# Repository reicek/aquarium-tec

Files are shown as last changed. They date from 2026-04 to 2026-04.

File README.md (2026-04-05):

# Aquarium TEC Cold Block Prototype

This repository contains the current engineering baseline for a custom inline TEC chiller for an 8 gallon aquarium. The project is built around a low-restriction cold block, a staged prototype-to-CNC manufacturing path, and a first powered prototype that keeps the controller, HMI, and high-current TEC hardware explicit and orderable.

## What This Repo Holds

- A parametric OpenSCAD model for the cold block, hose-plug options, and interlocking powered-prototype support kit.
- Reference SVG sheets for the mechanical design and the powered-prototype electrical package.
- BOM, RFQ, validation, and controller-planning documents under `agent/` and `rfq/`.
- Quote-ready notes for both the PLA fit prototype and the final hybrid CNC wet-part set.

## Current Baseline

Mechanical baseline:

- Inline cold block body: 140 x 92 x 24 mm, excluding hose plugs.
- Internal water path: 6 straight channels with a 14.5 mm minimum bore through the full path.
- Lid/base split: 8 mm lid, 16 mm base.
- Thermal stack: 50 x 50 mm TEC, 60 x 60 x 5 mm copper spreader, Intel LGA1700 / LGA1851 hot-side mount.
- Hose-plug baseline: separate trapped plugs, with the current documentation assuming the 16.0 mm OD option on both ports.
- Final wet-part direction: 316L stainless lid, CNC POM base, and CNC POM hose plugs.

Powered prototype baseline:

- Main PSU: Mean Well LRS-350-24.
- TEC driver: IBT-2 Double BTS7960 43 A module.
- Logic buck: TOBSUN EA15-5V, 24 V to 5 V, 3 A.
- Controller: Seeed Studio XIAO nRF52840 Plus.
- Local HMI: Seeed Studio Round Display for XIAO.
- Hot-side cooler: Thermalright Assassin X 120 Refined SE.
- Hot-side fan: Noctua NF-F12 industrialPPC-24V-2000 IP67 PWM.
- Sensors: DS18B20 set, Adafruit SHT31-D, DFRobot SEN0205, and Mallory PS-580Q local alarm.

Prototype rules that remain important:

- The printed wet-path parts are for fit and dry assembly only.
- The 24 V and 5 V rails are the only rails in the current exact powered-prototype package.
- The final hose-plug OD is still gated on physical hose-fit testing.

## Key Docs

- [tec_cold_block_mockup.scad](tec_cold_block_mockup.scad): source-of-truth OpenSCAD model.
- [fabrication_notes.md](fabrication_notes.md): high-level geometry, usage, and file notes.
- [agent/mechanical_design.md](agent/mechanical_design.md): frozen geometry, support-frame intent, and manufacturing notes.
- [agent/system_bom.md](agent/system_bom.md): working BOM.
- [agent/powered_prototype_order_list.md](agent/powered_prototype_order_list.md): current buy-list freeze for the powered prototype.
- [agent/powered_prototype_wiring_diagram.md](agent/powered_prototype_wiring_diagram.md): harness IDs, cut lengths, and wiring topology.
- [agent/validation_and_open_items.md](agent/validation_and_open_items.md): validation gates and still-open items.
- [rfq/pla_prototype/pla_prototype_rfq_package.md](rfq/pla_prototype/pla_prototype_rfq_package.md): PLA prototype package.
- [rfq/final_hybrid_cnc/final_hybrid_cnc_rfq_package.md](rfq/final_hybrid_cnc/final_hybrid_cnc_rfq_package.md): final hybrid CNC package.

3D Renders



- Side


- Top


- Front


- Back


## SVG Gallery

### Whole Block Reference

Shows the assembled cold block reference view.

Whole block reference

### Lid Reference

Shows the lid-owned geometry, channel pack, and thermal face role.

Cold block lid reference

### Base Reference

Shows the base-owned geometry, seal groove, and lower water-path role.

Cold block base reference

### Hose-Plug Options

Shows the current 16.0 mm, 15.4 mm, and 14.8 mm hose-plug options.

Hose plug options reference

### Combined Cold Block Overview

Shows the block, lid, base, and hose-plug option set in one reference sheet.

Combined cold block overview

### Powered Prototype Component Layout

Shows the 2D component placement baseline for the powered prototype support assembly.

Powered prototype component layout

### Powered Prototype Electrical Block Sheet

Shows the detailed color-coded wiring diagram for the same powered prototype baseline.

Powered prototype electrical block sheet

## Manufacturing Path

Stage 1, PLA fit prototype:

- Validate hose fit, assembly access, clamp access, support-frame part fit, and service clearance.
- Do not use the printed cold block as the final wet-path part.

Stage 2, final hybrid CNC wet parts:

- Machine the lid from 316L stainless steel.
- Machine the base and hose plugs from POM.
- Keep the full-bore path and smooth diffuser/converger surfaces.
- Hold final wet-part release until hose-plug fit is locked from the real hose.

## Export And Verification

Available VS Code tasks include:

- `Export OpenSCAD Prototype STL Set`
- `Verify OpenSCAD Prototype STL Layouts`
- `Export OpenSCAD Prototype Support Service STL Set`
- `Export OpenSCAD Hybrid STL Set`
- `Export OpenSCAD Hybrid STEP Set`

Useful output folders:

- [rfq/pla_prototype/stl](rfq/pla_prototype/stl)
- [rfq/pla_prototype/exports](rfq/pla_prototype/exports)
- [rfq/final_hybrid_cnc/stl](rfq/final_hybrid_cnc/stl)
- [rfq/final_hybrid_cnc/step](rfq/final_hybrid_cnc/step)

## Open Gates

- Final hose-plug OD still depends on real hose-fit results.
- Final clamp size still depends on the chosen hose-plug OD and real hose measurements.
- Final wet-part seal cut length still depends on the released groove measurement.
- The controller PCB is still a planned deliverable, not a finished schematic/layout release.
- Leak-threshold calibration still remains a firmware and bring-up task.

## Practical Reading Order

1. Start with [fabrication_notes.md](fabrication_notes.md) for the repo overview.
2. Read [agent/mechanical_design.md](agent/mechanical_design.md) for the frozen geometry and support-frame intent.
3. Read [agent/system_bom.md](agent/system_bom.md) and [agent/powered_prototype_order_list.md](agent/powered_prototype_order_list.md) for the current hardware baseline.
4. Read [agent/powered_prototype_wiring_diagram.md](agent/powered_prototype_wiring_diagram.md) together with the two powered-prototype SVG sheets.
5. Use the RFQ packages when preparing quotes or exports.

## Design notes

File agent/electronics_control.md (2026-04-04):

# Electronics And Control

This file describes the preferred electrical architecture for the prototype and the path to a cleaner production-style build.

## Control architecture philosophy

First revision should separate logic and sensing from the high-current TEC power stage.

Recommended split:

- XIAO nRF52840 Plus plus Round Display handle local HMI, BLE telemetry, and core control logic
- custom interface or interposer board handles sensor connectors, conditioned driver signals, power entry, and access to the Plus-only additional pads
- external TEC driver handles 24 V power switching in the first revision

Why:

- lower integration risk
- easier PCBWay assembly
- easier bench debugging
- avoids forcing the first custom PCB to solve both logic and power-stage problems at the same time

## Power tree

Recommended structure:

- 24 V main input from PSU
- direct 24 V branch to TEC driver
- fused low-current 24 V branch to the logic buck
- 24 V to 5 V buck for the XIAO, Round Display, and low-current logic rail
- direct 24 V branch to the current prototype fan
- no 12 V rail in the current exact prototype build; keep a 24 V to 12 V buck only as a fallback if the stock 12 V cooler fan is reinstated later

Important constraint:

- raw 24 V must not be routed to the XIAO Plus or Round Display; the powered prototype must pass through the 24 V to 5 V logic buck first

Practical baseline parts:

- main PSU: Mean Well LRS-350-24, approved project baseline PSU
- logic converter: TOBSUN EA15-5V, required for the powered prototype until the controller board exists
- hot-side fan path: Thermalright Assassin X 120 Refined SE heatsink with a Noctua NF-F12 industrialPPC-24V-2000 IP67 PWM replacement fan
- optional fallback fan converter: Pololu D24V10F12 only if the stock 12 V cooler fan is kept instead of the 24 V Noctua replacement

Logic power budget note:

- the Round Display itself is low power, but the total 5 V budget should assume XIAO, display, sensors, and interface buffer overhead
- a 5 V rail sized for at least 500 mA continuous is comfortable; 1 A is preferred margin

## TEC driver strategy

Approved prototype baseline:

- external IBT-2 Double BTS7960 43A H-bridge module

Current engineering stance:

- approved for the first powered prototype
- not automatically trusted for long-term continuous-duty use

Important issue:

- the XIAO Plus is 3.3 V logic only
- many generic driver modules are sold as 5 V logic accessories
- do not assume logic compatibility without verification

Engineering recommendation:

- either verify the driver input thresholds on the exact module used
- or insert a proper logic-level translator / buffer between XIAO and driver
- the preferred rev-1 solution is a Texas Instruments SN74AHCT125PW powered from 5 V; treat it as standard in rev 1 unless the received IBT-2 board is fully verified for 3.3 V logic and safe defaults

## Control method

Do not use relays for TEC power modulation.

Use:

- transistorized driver stage
- PWM or current-modulated control through the driver

Prototype control notes:

- the TEC does not need polarity reversal for a pure cooling system, but an H-bridge keeps that option available
- if future integration prefers a simpler direction, a one-quadrant power stage could replace the H-bridge later

## Recommended sensors

Recommended rev-1 temperature set:

- one water temperature sensor for actual aquarium temperature control
- one hot-side sensor on the CPU cooler base or near the hot plate
- one cold-block sensor on the exchanger body
- one air intake temperature sensor placed upstream of the cooler fan and used as the ambient intake reference
- one air outlet temperature sensor placed in the cooler exhaust stream

Strongly recommended additional sensors:

- ambient humidity sensor near the insulated block to watch condensation risk
- leak sensor in the cabinet or below the block

Why the extra air sensors are worth adding:

- intake air temperature gives a real ambient baseline for hot-side performance and condensation calculations
- outlet air temperature gives a quick check on heatsink delta and airflow health
- intake-to-outlet trend data helps catch fan failure, fin blockage, or exhaust recirculation earlier than the base sensor alone

Recommended sensor types:

- Adafruit Waterproof DS18B20, PID 381, for water temperature unless the stock probe already on hand is reused
- Analog Devices DS18B20+ in TO-92 package for the hot side
- Analog Devices DS18B20+ in TO-92 package for the cold block
- Analog Devices DS18B20+ in TO-92 package for intake air
- Analog Devices DS18B20+ in TO-92 package for outlet air
- Adafruit SHT31-D breakout, PID 2857, for ambient condensation monitoring
- DFRobot Gravity Water Sensor, SEN0205, as the current exact prototype leak-sensor choice

Rev-1 integration recommendation:

- standardize water, cold-block, hot-side, intake-air, and outlet-air on one shared 1-Wire bus
- DS18B20 is now the chosen rev-1 temperature family for all five points
- exact attachment method for the hot-side and cold-block sensors is still a mechanical packaging detail, but no extra analog temperature channel is planned

Bus-sharing note:

- the Round Display already occupies D4 and D5 for I2C-based RTC and touch functions
- the humidity sensor can still share this I2C bus if pull-ups and address assignments are kept sensible
- a shared DS18B20 bus lets water, cold-block, hot-side, intake-air, and outlet-air probes share a single extra GPIO on the Plus-only pad set
- use the SEN0205 as the current exact leak-sensor part for the dry-build prototype and treat the controller-side channel as a thresholded leak input during harness bring-up

## Safety and fail-safe behaviors

The controller should be designed around fault containment, not just temperature control.

Minimum failsafes:

- if hot-side temperature exceeds threshold, reduce or stop TEC drive
- if water temperature sensor becomes invalid, stop TEC drive and raise alarm
- if hot-side temperature rises while the outlet-air minus intake-air delta collapses, assume airflow trouble and reduce or stop TEC drive
- if intake air temperature is unusually high, derate expected cooling capacity or raise an operator warning
- if humidity rises to condensation-risk levels, limit cooling aggressiveness or alarm
- if leak sensor trips, stop TEC and alarm
- if XIAO watchdog triggers, force the TEC driver to a safe disabled state

Electrical protection recommendations:

- branch fuses
- reverse-polarity protection on the low-current logic input
- TVS or surge protection on external sensor lines if they are long
- pull-down or pull-up states that leave the TEC disabled by default at MCU reset

## XIAO Plus and Round Display architecture

The control subsystem should be treated as an HMI stack plus an interface board, not a bare XIAO dev board.

Preferred architecture:

- U1: Seeed Studio XIAO nRF52840 Plus
- U2: Seeed Studio Round Display for XIAO
- PCB1: custom interface or interposer board assembled by PCBWay
- U3: external TEC driver module in prototype phase

Interface-board purpose:

- mount or interconnect the XIAO Plus cleanly
- preserve or replicate the standard XIAO header geometry needed by the Round Display
- break out the Plus-only additional pads to usable connectors or nets
- provide regulated power distribution
- provide driver interface conditioning
- expose SWD pads and debugging access
- keep antenna area clear

Recommended board philosophy:

- 4-layer FR-4
- ENIG finish
- good ground reference for logic and sensor work
- keep high current off this board in revision 1

What the board should include:

- XIAO Plus module footprint using the official Seeed module data
- mating geometry for the Round Display based on the standard XIAO pin rows
- 24 V input connector for auxiliary power only, not TEC current path
- 5 V buck stage or a clearly documented 5 V input path from an external buck module; for the current powered prototype, the external TOBSUN EA15-5V module is mandatory
- JST-VH for the 24 V auxiliary input, JST-PH for low-current sensor I/O, and JST-XH for the driver-control link
- one dedicated 3-pin temperature-bus connector for the shared five-probe DS18B20 harness
- separate low-current connectors for humidity and leak sensing
- 1-Wire pull-up and a serviceable harness plan for the five DS18B20 temperature channels
- SN74AHCT125PW driver-interface buffer
- driver control connector
- alarm output
- Tag-Connect TC2030 compatible SWD pads
- optional local user button if not relying entirely on the touch display

What the board should not do in rev 1:

- switch 6 A TEC current directly unless the whole board is redesigned as a real power board
- crowd the XIAO antenna with planes, shields, or metal standoffs

## Round Display pin budget impact

The Round Display consumes almost the full standard XIAO header pin set.

Pins used by the Round Display stack:

- D1: LCD_CS
- D3: LCD_DC
- D4: I2C SDA for touch and RTC
- D5: I2C SCL for touch and RTC
- D7: touch interrupt
- D2: microSD chip select
- D8, D9, D10: SPI for microSD
- D6: screen backlight control on the display board when the KE switch is in the display position
- D0: battery measurement path on the display board when the KE switch is in the display position

Implication:

- standard XIAO nRF52840 is too pin-starved for this project once the Round Display is added
- XIAO nRF52840 Plus is the correct variant because the additional pads can carry the non-HMI system I/O

## Suggested system I/O allocation

This is the schematic-planning map for rev 1.

- Standard XIAO pins reserved for Round Display: D1, D2, D3, D4, D5, D7, D8, D9, D10, and likely D6 and D0 depending the display switch position used
- Plus-only extra pad 1: 1-Wire temperature bus for water, cold-block, hot-side, intake-air, and outlet-air DS18B20 probes
- Plus-only extra pad 2: leak sensor input
- Plus-only extra pad 3: TEC_PWM to driver buffer
- Plus-only extra pad 4: TEC_EN to driver buffer
- Plus-only extra pad 5: TEC_DIR or second PWM line to driver buffer
- Plus-only extra pad 6: buzzer or alarm output
- Plus-only extra pad 7: fan tach input
- Plus-only extra pad 8: fan PWM output or spare digital output
- Plus-only extra pad 9: spare service input, interlock, or future flow switch

Exact mapping of these functions to the official Plus pad names should follow Seeed's official symbol and footprint during actual schematic capture.

Exact mechanical attachment of the hot-side and cold-block DS18B20 sensors should be decided during packaging, not during pin-budget planning.

## Preferred DS18B20 connector and harness layout

Board-side connector strategy:

- use one board-side connector for the shared temperature bus, not five parallel temperature connectors on the PCB
- recommended connector class for the rev-1 temperature bus: keyed 3-pin JST-PH class or equivalent serviceable locking connector
- pin order should be fixed and documented as 3V3, 1WIRE_TEMP, GND

Harness strategy:

- run the five temperature points in powered 3-wire mode, not parasite-power mode
- use one main 24 to 26 AWG three-conductor harness from the controller board to a splice point near the prototype support frame and thermal assembly
- from that splice point, make four short local drops to cold-block, hot-side, intake-air, and outlet-air sensors
- make the water-temperature branch the only longer run and route it with the hose or water line path instead of letting it dangle near the fan wiring
- label each branch clearly as T_WATER, T_COLD, T_HOT, T_AIR_IN, and T_AIR_OUT

Practical routing rules:

- keep the four local air and block sensor branches as short as practical so the 1-Wire bus behaves like one trunk with short stubs rather than a large star
- keep the humidity and leak wiring off the temperature harness entirely
- place the single 1-Wire pull-up on the controller board only; do not duplicate pull-ups in the harness or sensor pigtails
- keep the temperature harness on the sensor edge of the board, away from the TEC driver wiring bundle

## Rev-1 DS18B20 placement and lead targets

Reference routing point:

- place S_TEMP on the inside face of the rear panel, centered in X, below the driver shelf and about 25 to 35 mm above the top of the block
- treat all local branch lengths below as measured from S_TEMP to the active sensing tip, not from J3
- target branch lengths should include one small service loop but should not leave large unused coils near the fan or driver wiring

Temperature harness target lengths:

- H_TEMP trunk from J3 to S_TEMP: 280 mm target
- T_WATER branch: 1200 mm target, then trim only after the full tank and cabinet routing is confirmed
- T_COLD branch: 200 mm target
- T_HOT branch: 180 mm target
- T_AIR_IN branch: 220 mm target
- T_AIR_OUT branch: 100 mm target

Exact rev-1 mounting locations:

- T_WATER: immerse in the display tank at mid-depth, away from the return jet and away from the cold block assembly, with the sensing tip at least 100 mm from the filter return stream and not resting on the glass or substrate
- T_COLD: bond to the display-side outer wall of the cold-block body, centered on the straight-channel region at about mid-length of the block, roughly 8 to 10 mm above the block bottom and safely below the lid-base split plane
- T_HOT: bond to the exposed cooler-base shoulder or first heat-pipe root zone, on the side of the base that remains accessible after the fan is installed, with the sensing tip as close as practical to the copper spreader plane and kept out of the direct fin-pack airflow
- T_AIR_IN: suspend the sensing tip in the intake gap between the display mast side and the cooler fan face, about 12 to 15 mm ahead of the fan intake plane and about 20 to 25 mm off the fan hub center so it sees moving air instead of the dead zone at the hub
- T_AIR_OUT: suspend the sensing tip in the exhaust gap between the cooler rear face and the PSU side, about 3 to 5 mm behind the rear fin face and about 20 to 25 mm off the hub center, without letting the probe touch the PSU panel, rear shelf, or fin edges

Mounting method guidance:

- T_COLD and T_HOT should use a thin bonded attachment method such as thermally conductive epoxy, aluminum tape plus strain relief, or a compact clamped tab that does not add much thermal mass
- T_AIR_IN and T_AIR_OUT should be supported by a light clip, loom tie, or heat-shrink standoff so the sensing tip sits in the airstream and not against metal or ABS
- T_WATER should use its factory waterproof encapsulation directly and should not share a cable sleeve with the TEC power wiring

## Wireless design note

The stainless block, CPU cooler, PSU, and enclosure metal can all hurt BLE performance.

Design implication:

- place the XIAO near a plastic wall or open air edge of the enclosure
- keep the antenna end away from the wet block and away from large ground pours
- if necessary, use a short cable to physically separate the controller board from the thermal assembly

## Preferred bring-up order

1. power the XIAO and sensors from a bench supply or the TOBSUN EA15-5V logic buck only
2. validate Round Display bring-up using the Arduino GFX or Seeed_GFX path
3. validate sensor readings and BLE behavior
4. connect the external TEC driver with no TEC attached
5. verify safe default states and PWM behavior through the level-shift or buffer stage
6. attach the TEC and hot-side cooling
7. enable thermal testing with water loop last

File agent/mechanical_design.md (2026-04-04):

# Mechanical Design

This file captures the current frozen geometry and the manufacturing intent for the inline cold block.

## Current geometry

Overall body, excluding hose plugs:

- length: 140 mm
- width: 92 mm
- total thickness: 24 mm
- lid thickness: 8 mm
- base thickness: 16 mm

Thermal landing:

- landing area: 64 x 64 mm
- critical flat contact zone: at least 52 x 52 mm
- intended TEC size: 50 x 50 mm
- intended copper spreader size above TEC: 60 x 60 x 5 mm
- hot-side cooler mount pattern: Intel LGA1700 / LGA1851, 78 x 78 mm square, 4.3 mm clearance holes

Water cavity:

- cavity envelope: 112 x 62 x 6 mm
- roof thickness above cavity: 2 mm nominal
- internal side wall thickness: 0 mm dedicated side walls
- inlet diffuser length: 28 mm
- outlet converger length: 28 mm

Channel pack:

- 6 channels
- each channel: about 8.67 x 56 x 6 mm
- fin width between channels: 2 mm
- side walls removed so the outer channels run to the cavity edges
- total open area in channel pack: about 312 mm^2

Hydraulic comparison:

- target hose ID: 14.5 mm
- hose area at 14.5 mm ID: about 165 mm^2
- channel pack open area: about 312 mm^2

Conclusion:

- the channel pack is not supposed to be the hydraulic bottleneck
- the internal bore and transition quality matter more than adding more channels

## Hose plugs and bore

Current SCAD / prototype baseline:

- the preview model now shows separate trapped hose plugs
- hose-plug projection on the full prototype preview: 24 mm
- installed main hose-plug OD: 16.0 mm
- extra hose-plug option ODs: 15.4 mm and 14.8 mm
- minimum internal bore: 14.5 mm
- port axis offset: about 1.25 mm below the lid/base split plane to preserve lid roof thickness

Final wet-part direction:

- use separate replaceable hose-plug pieces, one per port
- trap each hose plug between lid and base so it cannot move in or out while the block is clamped
- use a rounded-square or four-flat anti-rotation interface rather than a sharp square corner
- keep the full 14.5 mm minimum bore through each hose plug and blend smoothly into the diffuser / converger
- keep the hose-clamp bead close to the block face so hose bending load does not create a long moment arm at the plug root

Design intent:

- smooth outside for hose fit
- no barbed geometry that forces a hidden bore restriction
- use external clamp retention rather than aggressive barb teeth
- allow hose-plug OD changes later without remachining the lid

## Seal concept

Current groove baseline:

- groove centerline rectangle: 116 x 68 mm
- groove width: 2.4 mm
- groove depth: 1.5 mm
- intended seal cross section: 2 mm

Seal direction:

- prototype phase can use seal cord or gasket-equivalent for fit confirmation
- final hybrid phase should use EPDM or silicone compatible with aquarium use
- if the final rectangular O-ring is not easy to source, seal cord or custom gasket is acceptable as long as compression is controlled
- do not rely on tapped plastic alone for clamp load; use through-bolts, washers, and compression control across the POM base

## Material strategy

Prototype geometry validation:

- PLA is preferred for the first low-cost fit, size, clamp access, and general assembly checks
- if PCBWay process selection makes PLA awkward, ABS or another rigid prototype plastic is acceptable for fit-only work

Final wet-part baseline:

- lid: 316L stainless steel
- base: CNC POM
- separate hose plugs: CNC POM

Materials explicitly avoided in the water path:

- aluminum
- brass
- mixed unknown plated fittings
- coated 3D-printed wet parts as final-release hardware

## Surface finish and tolerance intent for the final hybrid part

Because this is a wet precision prototype, the surface requirements should be explicit.

Critical zones:

- TEC landing face in the lid: flat and smooth, target flatness 0.05 mm or better, target finish Ra 0.8 um or better
- bore transitions and diffuser surfaces: deburred and polished, no chatter ridges left in the flow path
- O-ring groove in the POM base: clean and burr-free, with no rolled edges that could damage the seal
- hose-plug outside surfaces and bead geometry: smooth and dimensionally stable for hose fit

Preferred wet-part post-process:

- deburr all edges
- hand polish the diffuser / converger surfaces in the metal lid if machining marks remain
- passivate the final 316L lid after machining
- machine the POM base and hose plugs from solid stock; do not rely on a coating over a printed part for the final water barrier

Optional premium finish:

- electropolish plus passivation if quote and schedule permit

## Why the geometry got larger than the early concept

The part was intentionally enlarged to 140 x 92 x 24 because the compact draft could not honestly support all of these at once:

- full 14.5 mm internal bore
- 2 mm roof over the wet cavity
- smooth transitions
- adequate wall thickness
- earlier integrated spigot concept

The larger block is not wasted size. It is the cost of making the hydraulic and mechanical goals coexist.

## Prototype support frame

The powered-prototype baseline now includes an interlocking support kit so the cooler, PSU, and local HMI can be packaged around the block without committing to a full enclosure.

Current support-frame intent:

- overall footprint: about 248 x 190 mm
- packed print bundle: current `prototype_support_frame.stl` validates at about 282.9 x 240 x 8 mm
- support height under block: 8 mm cradle beams
- block position: supported from below in a ladder-style cradle, not suspended from the cooler holes
- display side: one low-profile side mast with a 34 mm screen window, the XIAO retained below the display in the lower opening band, and a split relief that trims the mast to about 116 mm overall while preserving the exact 43 x 43 mm Round Display mount pattern
- PSU side: split rear structure rather than a full wall, using two fixed-hole Mean Well LRS-350-24 side-mount uprights aligned to the 150 mm long-axis hole pitch, a narrow center driver spine, a rear-facing Double BTS7960 mount with the heatsink outboard, and a compact tie-slot landing on the lowest part of that same spine for an external 24 V to 5 V logic buck below the driver; keep the large pass-through window above the buck zone and preserve the widened lower cable notch for the capacitor and cable exit
- support construction: interlocking flat-print kit rather than a single monolithic print, so the cradle, rear deck, mast, uprights, spine, shelf, and small locator parts can be replaced individually
- support joints: use hidden matching witness letters on the actual mating faces and light self-locating detents in the printed joints so alignment is obvious during assembly but the marks disappear once fully seated
- driver shelf joint: rely on the shelf-to-spine interlock only for rev 1; do not add separate shelf legs unless testing shows the shelf needs them
- serviceability: keep individual support sub-part wrappers available for one-piece reprints, and keep simple engraved part IDs on the printed pieces so the kit is easy to sort and reassemble
- hose handling: low strain-relief tabs tucked close to the block base and aligned to the shifted hose-plug bead position so hose spring force and clamp load stay near the block, not at the tube tip

Design stance:

- the 78 x 78 mm Intel LGA1700 / LGA1851 pattern stays the cooler clamp interface
- it should not become the main structural path for the support frame
- the block cradle should carry the static load and the hose side load instead

### Rev-1 sensor placement around the support frame

Temperature harness physical baseline:

- one shared DS18B20 splice point should sit on the inside face of the rear panel, centered laterally and below the driver shelf
- route the main temperature trunk from the controller side to that splice point along the sensor side of the frame, not through the TEC driver wiring bundle
- keep only the water probe as the long run; all other probe branches should terminate within the powered prototype envelope

Local mounting targets:

- cold-block probe: display-side outer wall of the block, centered on the straight-channel zone and below the split plane
- hot-side probe: exposed cooler-base shoulder or first accessible heat-pipe root near the copper spreader plane
- intake-air probe: in the gap ahead of the cooler fan on the display side, offset from the hub centerline
- outlet-air probe: in the narrow exhaust gap behind the cooler and ahead of the PSU side hardware, offset from the hub centerline and clear of metal contact

Lead-length targets from the splice point:

- cold-block: about 200 mm
- hot-side: about 180 mm
- intake-air: about 220 mm
- outlet-air: about 100 mm
- water probe: about 1200 mm from the splice point to the aquarium sensing location

## What must stay frozen until hose-plug testing

These are currently fixed:

- 6-channel core
- 14.5 mm minimum internal bore
- 28 mm transitions
- no threaded fittings in the first version
- straight parallel channel architecture

These are intentionally still variable:

- final hose-plug OD
- exact clamp type
- exact trapped hose-plug interlock geometry and whether the plug root needs a dedicated secondary seal
- exact Double BTS7960 hole-center map and final retention method if the flat-mounted board is later converted from a plain ledge support to a board-specific screw or strap pattern
- exact display mounting-hole pattern once the powered prototype hardware is in hand

## Manufacturing notes for PCBWay

For the final hybrid lid/base/plug set, ask for:

- CNC machining only
- no hidden bore reduction
- no media blasting inside the wet passages
- leak test before shipment
- sharp internal corners replaced with realistic CNC radii where necessary
- photographs of the finished lid landing face, base groove, and hose plugs before shipping if possible

## Related files

- parent SCAD model: `../tec_cold_block_mockup.scad`
- parent full-block preview: `../whole_block_preview.svg`
- parent lid preview: `../cold_block_lid_preview.svg`
- parent base preview: `../cold_block_base_preview.svg`
- parent hose-plug option preview: `../hose_fit_coupons_preview.svg`
- parent combined preview: `../cold_block_combined_preview.svg`

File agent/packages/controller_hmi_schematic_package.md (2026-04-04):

# Controller And HMI Schematic Package

This file is the schematic-ready package for the first controller revision after adding the Round Display and switching to the XIAO nRF52840 Plus baseline.

## Design intent

Build a controller subsystem that:

- uses the Seeed Studio XIAO nRF52840 Plus as the wireless controller
- uses the Seeed Studio Round Display for XIAO as the local screen and touch HMI
- preserves the standard Round Display pin mapping
- uses the Plus-only additional pads for non-HMI system I/O
- keeps the 24 V / 6 A TEC power stage off-board in rev 1

## Recommended board name

TEC-HMI-CTRL-REV1

## Architecture summary

Preferred block structure:

- J1: 24 V auxiliary input from main PSU branch
- U1: Seeed Studio XIAO nRF52840 Plus
- U2: Seeed Studio Round Display for XIAO mating interface
- U3: Texas Instruments SN74AHCT125PW driver buffer for the TEC-driver control link
- U4: TOBSUN EA15-5V or an electrically equivalent 24 V to 5 V logic power stage
- J2: external TEC driver control connector
- J3: shared DS18B20 temperature-harness trunk connector
- J4: auxiliary I2C or humidity sensor connector if not placed on board
- J5: leak sensor connector
- J6: fan tach and PWM connector if needed
- J7: buzzer or alarm connector
- TP1..n: SWD and debug test pads

## Board philosophy

- 4-layer FR-4
- 1.6 mm
- ENIG
- moderate logic density, no aggressive miniaturization
- prioritize antenna clearance, connector clarity, and serviceability

## Power rails

Primary rails:

- +24VAUX: low-current branch derived from the main 24 V PSU
- +5V_HMI: feeds XIAO VBUS path and the Round Display subsystem
- +3V3_LOGIC: derived from XIAO or a local regulated rail for sensors and pull-ups
- GND_LOGIC: common logic ground tied to driver and PSU ground at the board entry strategy

Power rule:

- +24VAUX must feed the 5 V buck stage first; do not route raw 24 V into XIAO VBUS or the Round Display

Recommended power assumptions:

- target at least 500 mA on the 5 V logic/HMI rail
- 1 A 5 V capacity is preferred margin

## Functional blocks

### U1: Main controller

- Part: Seeed Studio XIAO nRF52840 Plus
- Function: BLE, application logic, HMI logic, sensor acquisition, alarms, TEC driver command generation

### U2: HMI display

- Part: Seeed Studio Round Display for XIAO
- Function: local screen, touch input, RTC, optional microSD

### U3: Driver interface buffer

- Part: Texas Instruments SN74AHCT125PW
- Reason: protect against unknown logic thresholds on generic IBT-2 / BTS7960 modules and make safe-default biasing easier to control
- Suggested signals through buffer:
  - TEC_PWM
  - TEC_EN
  - TEC_DIR

### U4: 24 V to 5 V logic power stage

- This stage is mandatory for the powered prototype; the XIAO Plus and Round Display must never be fed from raw 24 V
- Current exact powered-prototype part is the TOBSUN EA15-5V fed from the fused 24 V auxiliary branch
- Until the custom interface board exists, use this enclosed external fixed 5 V buck module rather than a generic open-frame buck board
- Current support baseline reserves a lower rear-face tie-slot mount below the BTS7960 on the center spine for this module
- Current preview assumes a vertical mounted envelope of about 48 x 19 x 52 mm on that lower spine landing
- Rev 1 goal is reliability, not minimum BOM cost

## Standard XIAO pins reserved for the Round Display

Treat these as consumed by the Round Display stack:

- D1: LCD_CS
- D3: LCD_DC
- D4: SDA for touch and RTC, shared I2C bus
- D5: SCL for touch and RTC, shared I2C bus
- D7: touch interrupt
- D2: microSD CS
- D8: SPI SCK
- D9: SPI MISO
- D10: SPI MOSI
- D6: screen backlight control when the display switch is in the display function position
- D0: display battery measurement path when the display switch is in the display function position

## Plus-only additional pad allocation

Use the additional XIAO Plus pads for the non-HMI system I/O.

Planning allocation:

- XP1: 1-Wire temp bus for all DS18B20 probes
- XP2: leak sensor threshold input
- XP3: TEC_PWM output
- XP4: TEC_EN output
- XP5: TEC_DIR output or second PWM output
- XP6: buzzer or alarm output
- XP7: fan tach input
- XP8: fan PWM output or spare digital output
- XP9: spare input for flow switch, door switch, or service mode

Note:

- exact pad names should be pulled from the official Seeed XIAO Plus symbol and footprint during actual schematic capture
- this package intentionally freezes the function map, not the exact symbol pin numbers

## Shared buses

### I2C bus

Shared on D4 and D5:

- Round Display RTC
- Round Display touch controller
- optional SHT31 humidity sensor

Design notes:

- check total pull-up strength
- avoid duplicate strong pull-ups if the display board already provides them

### 1-Wire bus

Shared on XP1:

- aquarium water DS18B20
- hot-side DS18B20
- cold-block DS18B20
- intake-air DS18B20
- outlet-air DS18B20

Design notes:

- one pull-up resistor only
- keep cable length reasonable
- use connector and cable conventions that make sensor replacement easy
- size the harness and labeling scheme for five probes from the start

## Connectors

### J1: 24 V auxiliary input

- type: JST B2P-VH(LF)(SN) board header with VHR-2N housing and SVH-21T-P1.1 contacts
- pins: +24VAUX, GND

### J2: External TEC driver control

- type: JST B5B-XH-A(LF)(SN) board header with XHP-5 housing and SXH-001T-P0.6 contacts
- pins:
  - 5V_REF or optional pull-up rail if needed
  - GND
  - TEC_PWM_BUF
  - TEC_EN_BUF
  - TEC_DIR_BUF

### J3: 1-Wire temperature bus

- type: JST B3B-PH-K-S(LF)(SN) board header with PHR-3 housing and SPH-002T-P0.5S contacts
- pins: 3V3, 1WIRE_TEMP, GND
- use powered 3-wire DS18B20 mode only; do not use parasite-power mode

### J4: Aux I2C or humidity sensor

- type: JST B4B-PH-K-S(LF)(SN) board header with PHR-4 housing and SPH-002T-P0.5S contacts
- pins: 3V3, SDA, SCL, GND

### J5: Leak sensor

- type: JST B3B-PH-K-S(LF)(SN) board header with PHR-3 housing and SPH-002T-P0.5S contacts
- pins: 3V3, LEAK_IN, GND

### J6: Fan monitor and control

- pins: 24V_FAN or external fan rail, GND, FAN_PWM, FAN_TACH

### J7: Alarm output

- pins: ALARM_OUT, GND

## Preferred temperature harness layout

Use one off-board harness for all five DS18B20 probes.

Board side:

- J3 is the only board-side connector for the 1-Wire temperature bus
- place J3 on the sensor edge of the board, not near the TEC driver connector
- keep the 4.7 kohm class 1-Wire pull-up on the board near the XIAO-side net source

Harness topology:

- H_TEMP: one 24 to 26 AWG three-conductor trunk from J3 to a splice point near the support frame and thermal assembly
- S_TEMP: one off-board splice node or compact harness junction, not five parallel PCB connectors
- branch T_WATER: longer branch routed with the water line or hose path
- branch T_COLD: short branch to the cold-block DS18B20
- branch T_HOT: short branch to the hot-side DS18B20 near the cooler base or heat-pipe root
- branch T_AIR_IN: short branch to the intake-air DS18B20 upstream of the fan
- branch T_AIR_OUT: short branch to the outlet-air DS18B20 in the exhaust stream

Harness rules:

- keep the four local thermal and airflow branches as short as practical so the bus acts like one trunk with short stubs
- keep humidity and leak sensors on their own connectors, not spliced into H_TEMP
- mark each branch with permanent heat-shrink or printed labels matching the firmware names
- keep the temperature harness separate from TEC current wiring and fan power where practical
- if a waterproof off-the-shelf DS18B20 probe includes a long factory cable, treat that as the branch lead and avoid adding another inline extension unless necessary

Target branch lengths from S_TEMP:

- H_TEMP trunk from J3 to S_TEMP: 280 mm target
- T_WATER: 1200 mm target
- T_COLD: 200 mm target
- T_HOT: 180 mm target
- T_AIR_IN: 220 mm target
- T_AIR_OUT: 100 mm target

Target mounting positions:

- S_TEMP: rear panel inside face, centered laterally, below the driver shelf and above the top-of-block envelope
- T_COLD: display-side outer wall of the cold block, centered on the straight-channel region and below the split plane
- T_HOT: exposed cooler-base shoulder or first accessible heat-pipe root near the spreader plane
- T_AIR_IN: 12 to 15 mm ahead of the fan intake face and 20 to 25 mm off the fan hub center
- T_AIR_OUT: 3 to 5 mm behind the rear fin face in the exhaust gap and 20 to 25 mm off the fan hub center
- T_WATER: mid-depth in the aquarium, away from the return jet and away from the glass-contact boundary layer

## Safety defaults

- TEC driver control lines must default to OFF at reset and during boot
- add pull-down or pull-up resistors as needed so the driver cannot self-enable at startup
- if the buffer is unpowered, its outputs must not unintentionally enable the driver

## PCB placement guidance

- place the XIAO antenna end at a board edge with minimal nearby copper
- keep the XIAO away from large metal when installed
- keep the Round Display mating geometry mechanically rigid and clearly keyed
- keep sensor connectors on one edge and the driver connector on a different edge to reduce wiring confusion
- keep SWD and USB access practical

## Firmware implications

- prefer Arduino GFX or Seeed_GFX for the Round Display on nRF52840 family
- do not plan around the TFT-only example path as the primary HMI software baseline
- use one shared 1-Wire bus for all temperature probes
- treat RTC as useful but optional if BLE time sync is adequate later

## Open items before schematic capture is fully frozen

1. exact XIAO Plus additional pad names from official Seeed symbol and footprint
2. verify input-threshold compatibility and safe-default behavior on the approved IBT-2 Double BTS7960 43 A driver, even though the SN74AHCT125PW is now the default rev-1 buffer choice
3. confirm whether the first controller board absorbs the 5 V stage or continues to rely on the external TOBSUN EA15-5V during prototype bring-up
4. confirm the firmware leak threshold and calibration method for the SEN0205 on the prototype harness
5. whether the Round Display is assembled by PCBWay or installed by the user after board delivery

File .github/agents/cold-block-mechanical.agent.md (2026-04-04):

---
name: "Cold Block Mechanical"
description: "Use for inline cold block geometry, flow restriction checks, hose fit, sealing strategy, material choice, PLA-first fit prototype prep, prototype print-layout optimization, SCAD-to-SVG reference accuracy, and CNC wet-part release notes."
tools: [read, edit, search]
user-invocable: false
---

You specialize in the mechanical and hydraulic side of the inline TEC cold block.

## Constraints

- keep the 6 straight-channel architecture unless test data justifies a change
- preserve the 14.5 mm minimum internal bore target
- do not recommend aluminum in the wet path
- treat the PLA-first plastic prototype as fit-validation only; ABS is a fallback if PLA quoting is awkward
- for any multi-part print export, keep parts tightly packed, broad flat exterior faces down, open internal geometry up, and hose-plug bores vertical with the hose ends up when practical
- for interlocking prototype joints, prefer hidden matching witness letters on the buried mating faces and light PLA-safe detents that help alignment without leaving exposed assembly marks after seating
- when editing section-view SVGs, clip blue water fills to block-owned internal volumes only
- for trapped hose plugs, show the separate plug pocket interface without implying lid-owned water in the base or base-owned groove geometry in the lid
- do not treat preview SVGs as production drawings; if release manufacturing is involved, require formal CAD plus a proper 2D drawing or PDF

## Approach

1. Read the cold-block geometry, fabrication notes, the shared professional drawing/CAD standard, and the current reference SVGs.
2. Check that SCAD, SVGs, dimensions, transitions, hose interfaces, and RFQ notes agree.
3. When editing manual SVG references, keep the repo palette consistent: charcoal outlines and text, blue water, green seals, amber thermal zones, and blue-gray hidden geometry.
4. When editing SVG references, use short leadered callouts for feature notes and push longer explanation into note boxes or divider-separated note bands.
5. When manufacturing documentation is in scope, enforce units, release status, critical-callout clarity, and explicit approval for geometry changes.
6. For multi-part print exports, choose print-optimal orientation first and then pack the parts into the smallest reliable XY footprint with a small justified gap.
7. For interlocking support-kit parts, place assembly cues on hidden mating faces and use minimal self-locating detents rather than exposed face labels or aggressive clips.
8. Prefer simple, machinable, low-restriction geometry.

## Output

- direct mechanical recommendations
- SCAD-consistent SVG reference fixes when documentation drifts
- quote-ready notes when manufacturing is involved

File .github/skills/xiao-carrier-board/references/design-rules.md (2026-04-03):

## Hard Rules

- Treat all XIAO user I/O as 3.3 V logic.
- Do not assume generic driver-module inputs are safely 3.3 V compatible without verification.
- Keep the XIAO antenna end clear of copper pours, shields, large metal, and the stainless block.
- Keep the high-current TEC path off the rev-1 XIAO carrier board.
- Reserve the standard XIAO header pins for the Round Display unless a deliberate redesign says otherwise.
- Use the XIAO nRF52840 Plus additional pads for non-HMI system I/O.

## Controller Functions The Rev-1 Board Should Own

- water temperature input
- hot-side temperature input
- cold-block temperature input
- humidity input
- optional leak input
- alarm output
- TEC driver enable and control signals
- optional fan control or tach input
- Round Display interface preservation

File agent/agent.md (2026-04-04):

# Aquarium TEC Prototype Agent

This folder is the project memory and handoff package for the custom inline TEC chiller for an 8 gallon aquarium using a Fluval 107-class hose path.

The intent is to preserve the current engineering state so future sessions can continue from a stable baseline instead of rediscovering the same constraints.

## Project goal

Build a high-quality prototype aquarium chiller around a 50 x 50 mm TEC module, with:

- an inline custom heat exchanger instead of cooling the canister body
- low hydraulic restriction so the Fluval 107 and inline CO2 diffuser do not see excessive backpressure
- a two-stage manufacturing path: low-cost PLA fit prototype first, then a hybrid CNC wet-part release with a 316L lid and CNC POM base and plugs
- wireless monitoring and control using a Seeed Studio XIAO nRF52840 Plus
- a local HMI using the Seeed Studio Round Display for XIAO
- documentation written for practical RFQs to PCBWay

## Current design baseline

The project has converged on a custom inline cold block rather than a canister-bottom contact plate.

Reason:

- the plastic canister wall is too strong a thermal bottleneck
- a direct inline exchanger removes that bottleneck
- the hose size mismatch in off-the-shelf chillers pushed the design toward a custom full-bore exchanger

The current cold block baseline is:

- 6 straight parallel channels
- full-bore 14.5 mm minimum internal water path
- smooth 28 mm inlet diffuser and 28 mm outlet converger
- body excluding hose plugs: 140 x 92 x 24 mm
- lid/base split: 8 mm / 16 mm
- cavity envelope: 112 x 62 x 6 mm
- 6 channels, each about 8.67 x 56 x 6 mm
- 5 internal fins at 2 mm and no dedicated side walls
- 6 assembly screws after the side-center pair was removed
- current SCAD uses separate 24 mm hose plugs for the prototype and final hybrid baseline
- 4 x Intel LGA1700 / LGA1851 hot-side mounting holes on a 78 x 78 mm square
- open prototype support frame: about 248 x 190 mm footprint with block cradle, side display mast, compact rear vertical PSU panel with fixed Mean Well LRS-350-24 side-mount spacing, a rear-facing Double BTS7960 mount with the heatsink outboard plus a pass-through window and widened lower cable notch behind the board, and low hose strain-relief tabs aligned to the hose-plug bead position
- provisional installed hose-plug OD: 16.0 mm
- extra hose-plug option ODs: 15.4 mm and 14.8 mm
- final wet-part material split: 316L lid, CNC POM base, separate CNC POM hose plugs
- final wet-part direction: separate trapped hose plugs are now the active SCAD and package baseline

The current mechanical source files live one level above this folder:

- `../tec_cold_block_mockup.scad`
- `../whole_block_preview.svg`
- `../cold_block_lid_preview.svg`
- `../cold_block_base_preview.svg`
- `../hose_fit_coupons_preview.svg`
- `../cold_block_combined_preview.svg`
- `../fabrication_notes.md`

## Reference SVG conventions

- use a consistent palette: charcoal outlines and text, blue water, green seals, amber thermal zones, and blue-gray hidden geometry
- in section views, show blue water only inside block-owned internal volumes; do not let water overlays float over dry plug-capture pockets unless the plug or wetted throat is intentionally shown
- the SCAD and SVGs must stay aligned on the separate trapped hose-plug baseline; if the plug geometry changes, update the lid, base, whole, and combined sheets together
- combined overview sheets should reuse the dedicated lid and base reference geometry rather than looser sketches
- if reference SVGs are included with RFQ material, verify them against the current SCAD before relying on them

## Frozen decisions

These decisions are intentionally treated as fixed unless new test data invalidates them.

1. Use the custom inline exchanger approach, not canister-bottom cooling.
2. Use straight parallel channels, not an S-path or serpentine path.
3. Use 6 channels, not 7 or 9, because low head loss matters more than extra wetted perimeter in this application.
4. Keep minimum internal bore at or above the Fluval hose ID target of 14.5 mm.
5. Do not use aluminum in the wet water path.
6. Prototype the geometry in PLA first, then use a 316L lid with CNC POM base and separate CNC POM hose plugs as the default final wet assembly.
7. Use the Thermalright Assassin X 120 Refined SE as the current exact hot-side heatsink, pair it with a Noctua NF-F12 industrialPPC-24V-2000 IP67 PWM fan, and keep the copper spreader between TEC and cooler base.
8. Keep the high-current TEC driver separate from the XIAO logic board in the first electronics revision.
9. Use the Seeed Studio XIAO nRF52840 Plus as the main controller platform.
10. Use the Seeed Studio Round Display for XIAO as the screen and touch HMI.
11. Because the Round Display consumes most standard XIAO pins, use the Plus-only additional pads through a custom interface board instead of relying on the standard 2 x 7 header pins alone.

## Preferred system architecture

Mechanical and thermal stack:

- Thermalright Assassin X 120 Refined SE heatsink
- Noctua NF-F12 industrialPPC-24V-2000 IP67 PWM fan
- thermal paste
- 60 x 60 x 5 mm copper spreader
- thermal paste
- 50 x 50 mm TEC module
- thermal paste
- custom inline cold block
- open prototype support frame carrying the block from below and holding the side electronics package
- closed-cell insulation on cold block and adjacent tubing

Electrical architecture:

- 24 V main PSU
- dedicated TEC driver or H-bridge
- separate regulated logic supply for the XIAO
- no separate 12 V rail in the current exact prototype build because the cooler uses a 24 V fan
- sensor suite for water, hot-side, cold-side, intake-air / ambient, outlet-air, ambient humidity, and leak detection

Control architecture:

- XIAO nRF52840 Plus mounted on a custom controller or interposer PCB
- Round Display for XIAO used as the local screen and touch interface
- external driver for the TEC in prototype phase
- BLE telemetry and configuration
- sensor acquisition, alarms, fail-safes, and closed-loop cooling control

## Current electrical recommendations

Power supply:

- Locked: Mean Well LRS-350-24
- Output: 24 V, 14.6 A, 350.4 W
- Reason: enough headroom for the TEC, control electronics, cooling fan conversion losses, and continuous-duty margin

Prototype TEC driver:

- Locked for the first powered prototype: IBT-2 Double BTS7960 43A H-bridge module
- Quality-preferred option for later refinement: a better-qualified 24 V motor/H-bridge module or a custom MOSFET power stage

Important electrical note:

- the XIAO Plus uses 3.3 V logic only
- many generic H-bridge modules are sold as 5 V logic accessories, so the actual logic thresholds must be verified
- if there is any doubt, add a proper level shifter or gate buffer between the XIAO and the driver inputs

## Current thermal expectation

The inline custom exchanger should perform materially better than canister-body cooling.

Working estimate for an 8 gallon aquarium with this inline block, a 50 x 50 mm TEC, a competent hot side, and proper insulation:

- typical realistic hold: about 3 to 5 C below room temperature
- optimistic case: about 5 to 6 C below room temperature

This is still a prototype estimate, not a guaranteed result. The final result depends on room temperature, lighting, pump heat, tubing losses, and actual TEC operating point.

## Manufacturing philosophy

This prototype should be treated like a high-quality industrial development part, not a hobby rough draft.

Priority order:

1. dimensional correctness
2. hydraulic behavior
3. sealing reliability
4. corrosion safety in aquarium use
5. surface finish in critical thermal and wet areas
6. cosmetic appearance

Key manufacturing stance:

- over-engineer early
- avoid hidden restrictions
- do not mix unproven high-current power electronics with first-pass logic PCB work
- use PCBWay as a manufacturing service, but give them unusually explicit instructions

## Controller and HMI summary

The chosen controller platform is the Seeed Studio XIAO nRF52840 Plus because it gives:

- BLE and NFC capability
- low-power Nordic MCU platform
- same classic XIAO size as the standard nRF52840
- 9 additional GPIO available through Plus-only SMD pads, giving about 20 GPIO total
- enough I/O margin to survive the Round Display pin usage and still control sensors and the TEC driver

The chosen local HMI is the Seeed Studio Round Display for XIAO because it gives:

- 1.28 inch round capacitive touch display
- onboard RTC
- onboard battery-management hardware if ever needed
- microSD slot if local logging is added later
- a clean operator interface without building a custom screen board from scratch

Important implications:

- 3.3 V I/O only
- keep the onboard antenna clear of metal and ground planes
- do not mount the module too close to the stainless water block or CPU cooler if wireless range matters
- the Round Display consumes most of the standard XIAO pins, so the extra Plus pins are now strategically important
- design a custom interposer or interface PCB rather than trying to wire the whole system point-to-point

## File map

- `decision_log.md`: reasoning history, rejected options, and rationale
- `system_bom.md`: full project parts list with status and notes
- `system_bom.csv`: machine-friendly BOM seed for later PCBWay prep
- `mechanical_design.md`: frozen geometry, material, seal, and machining guidance
- `electronics_control.md`: power tree, driver strategy, sensor plan, and carrier-board concept
- `xiao_nrf52840.md`: technical details and project-specific implications of the XIAO board
- `pcbway_handoff.md`: PCBWay-oriented RFQ and file-prep notes for the plastic-fit, CNC, and PCB phases
- `validation_and_open_items.md`: prototype gates, test plan, and open decisions
- `packages/controller_hmi_schematic_package.md`: schematic-ready system package for the XIAO Plus, Round Display, and interface board
- `../rfq/pla_prototype/pla_prototype_rfq_package.md`: first PCBWay RFQ package for the PLA plastic fit mockup

## Immediate next actions

1. review the SCAD and SVGs visually
2. order the PLA mockup and hose-plug option set
3. use the prototype hose-plug results to lock the final hose-plug OD
4. freeze the hybrid lid/base/plug drawing and machining request
5. bring up the XIAO Plus plus Round Display HMI stack using Arduino GFX or Seeed_GFX, not the TFT-only path
6. decide whether the first electronics spin uses an external TEC driver module or a custom power stage

## Non-obvious risks to keep in mind

- the hose OD that fits well externally can still create thin wall thickness if the internal bore is kept full-size
- BLE range can collapse if the XIAO is buried near the stainless block, PSU, or CPU cooler metal
- a standard 12 V CPU fan may require a dedicated 24 V to 12 V buck rail
- a generic driver module may work electrically but still be the weak reliability link in the system
- plastic fit prototypes should only validate fit, access, envelope, and assembly logic, not sealing or thermal performance
- on the nRF52840 family, the Round Display is better treated as an Arduino GFX or Seeed_GFX target than as a TFT-only target
- the extra pads on XIAO Plus are not useful unless the custom interface board actually breaks them out

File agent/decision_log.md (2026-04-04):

# Decision Log

This file records the major design choices, what was considered, and why each choice landed where it did.

## Cooling approach

### Rejected: cooling the bottom of the Fluval 107 canister

Reason:

- the canister body is plastic, which becomes the dominant thermal bottleneck
- even with a spreader plate and insulation, the expected improvement below room temperature is modest
- thermal contact to the canister body is harder to control than a direct water-side exchanger

### Rejected: gel pack or reusable cold pad between TEC and canister

Reason:

- gel behaves like a poor thermal conductor in steady state
- it adds thermal resistance instead of spreading heat effectively
- it sacrifices the TEC temperature differential to the interface layer

### Selected: custom inline cold block in the hose path

Reason:

- removes the plastic wall bottleneck
- allows direct control of the hydraulic geometry
- allows matching the Fluval hose size much better than most off-the-shelf chillers
- easier to insulate properly

## Channel path geometry

### Rejected: serpentine or S-path core

Reason:

- too much pressure drop for a canister-filter loop that already has an inline CO2 diffuser
- larger risk of trapped air
- worse for debris tolerance even if the current water is clean
- non-uniform temperature across the TEC footprint

### Selected: straight parallel channels with plenums

Reason:

- lowest pressure drop for a given heat transfer area
- better thermal uniformity across the TEC footprint
- simpler machining
- lower clogging risk

## Channel count

### Considered: 7 channels

This was the earlier balanced concept. It already had enough open area relative to the hose but was not the lowest-head-loss option.

### Considered: 9 channels

Reason for rejection:

- smaller hydraulic diameter
- more machining complexity in stainless
- more pressure drop with marginal thermal benefit in this use case

### Selected: 6 channels

Reason:

- better hydraulic margin
- still plenty of water-side surface area
- channel set open area remains safely above hose area
- better fit for the stated priority: do not increase backpressure in the Fluval plus CO2 diffuser loop

## Internal bore strategy

### Early issue found

One earlier concept kept the channel pack open enough but used a 13.5 mm port bore. That would have created the real restriction.

### Selected correction

- keep the minimum internal bore at 14.5 mm or larger end-to-end
- use smooth round-to-plenum transitions
- avoid threaded fittings in the flow path for the first version

## Hose-plug strategy

### Selected for prototype

- separate replaceable hose plugs, one per port
- no threads required
- user plans to clamp the hose externally

Reason:

- lets the PLA prototype validate the same swappable hose-plug architecture planned for the final hybrid build
- avoids extra fittings in the flow path
- keeps hose OD changes isolated to the plug parts

### Hose-plug fit approach

The final OD is not yet frozen. The current strategy is:

- full block best guess: 16.0 mm OD
- option 1: 15.4 mm OD hose plug
- option 2: 14.8 mm OD hose plug

Reason:

- resolve hose grip in one prototype round using the real plug geometry
- do not lock the final hose-plug OD before physical hose-plug testing

### Selected for final wet revision

- separate replaceable hose plugs, one per port
- trapped anti-rotation plug interface between lid and base
- lid stays 316L stainless steel
- base and hose plugs move to CNC POM

Reason:

- keep metal only where the TEC landing and channel pack need it
- reduce final wet-part cost versus a full 316L block
- make hose-plug replacement or OD changes possible without remachining the lid

## Materials

### Rejected: aluminum in the wet path

Reason:

- poor choice for long-term aquarium water contact
- avoid corrosion and contamination risk

### Selected: 316L lid plus CNC POM base and hose plugs as default final wet architecture

Reason:

- lid keeps the TEC landing and channel pack in metal
- POM is a realistic CNC aquarium-contact plastic for the base and replaceable hose plugs
- easier cost target than a full 316L block

### Rejected for final wet release: coated 3D-printed plastic wet parts

Reason:

- coating integrity becomes the water barrier instead of the substrate
- seal grooves, bores, and clamp-load regions are poor places to depend on hand-applied coatings

## Manufacturing path

### Selected phase order

1. PLA prototype for fit and space validation
2. hybrid CNC lid, base, and hose-plug set after fit is confirmed
3. controller carrier PCB and wiring harness refinement

Reason:

- fastest way to de-risk geometry before paying for wet-metal machining

## Hot-side cooling

### Accepted: 230 W class CPU air cooler

Reason:

- adequate for the expected hot-side load in this prototype
- commonly available and easy to mount

### Important added decision

Use a copper spreader between TEC and CPU cooler.

Reason:

- many CPU cooler bases do not comfortably cover a full 50 x 50 mm TEC
- the copper plate reduces local thermal crowding and mechanical stress concentration

## Electronics architecture

### Selected controller

- Seeed Studio XIAO nRF52840 Plus

Reason:

- wireless capability
- enough interfaces for sensors and control
- small module form factor suitable for carrier-board assembly
- keeps the classic XIAO size while adding 9 additional SMD GPIO

### Selected local HMI

- Seeed Studio Round Display for XIAO

Reason:

- gives a compact touch screen and operator interface without designing a custom display PCB
- includes useful extras such as RTC and microSD
- matches the XIAO ecosystem already chosen for the controller

### Consequence of the HMI choice

The Round Display consumes most of the standard XIAO pins:

- D1, D3, D4, D5, D7 for display and touch control
- D2, D8, D9, D10 for the microSD path
- D0 and D6 may also be tied to battery readout and backlight depending on the board switch position

Therefore:

- standard XIAO nRF52840 is no longer an attractive baseline for this project
- XIAO nRF52840 Plus is the cleaner fit because the additional pads can carry the non-HMI system I/O
- the first custom board should be an interface or interposer board that can actually break out those additional pads

### Selected control-board philosophy

- first PCB revision should be a logic, sensor, and HMI interface board, not the full 24 V 6 A power stage

Reason:

- separates low-risk control PCB work from higher-risk power electronics
- makes PCBWay assembly easier
- allows reuse of a known external TEC driver during the first system bring-up
- makes it possible to use XIAO Plus additional pads while still mating to the Round Display

### Prototype driver status

- the approved first powered-prototype driver is the external Double BTS7960 43A H-bridge module
- a better-qualified driver still remains the later upgrade path if reliability becomes more important than cost

Reason:

- user-approved exact low-cost module for prototype bring-up is now known
- quality variation in clone modules is a known concern
- if reliability becomes more important than cost, a better-qualified driver should replace it

## Temperature sensing architecture

### Selected: DS18B20 for all rev-1 temperature channels

- aquarium water
- cold block
- hot side
- intake air / ambient reference
- outlet air

Reason:

- the user already has enough DS18B20 sensors on hand
- one shared 1-Wire bus keeps the Round Display pin budget manageable on the XIAO Plus
- it simplifies the carrier-board schematic, connector strategy, and firmware compared with mixing analog NTC and digital temperature paths
- it keeps the first controller PCB focused on logic and sensing, not extra analog conditioning circuits

Consequence:

- the Plus-only temperature input remains a single shared 1-Wire bus
- temperature-sensor electrical type is no longer an open item for rev 1
- the remaining open detail is mechanical attachment method for the hot-side and cold-block probes, not sensor family selection

### Selected: one board-side temperature-bus connector with an off-board five-drop harness

- one keyed 3-pin board connector for 3V3, 1WIRE_TEMP, and GND
- one powered 3-wire harness leaving the controller board
- one off-board splice point near the support frame or thermal assembly
- four short local drops for cold-block, hot-side, intake-air, and outlet-air probes
- one longer branch for the water probe

Reason:

- avoids wasting board area on five parallel temperature connectors
- keeps the PCB-side 1-Wire topology cleaner than a five-way star directly on the board
- improves serviceability because the whole temperature harness can be unplugged as one assembly
- fits the moderate-density, serviceable rev-1 carrier-board philosophy better than a connector-heavy board edge

## Performance expectation

### Updated expectation after switching to inline block

- custom inline block: about 3 to 5 C below room temperature is the working realistic goal
- optimistic: 5 to 6 C below room temperature with good insulation and favorable room heat load

This is considered a prototype performance estimate, not a locked guarantee.

## Controller family alternatives considered

### Considered: XIAO ESP32S3 or XIAO ESP32S3 Plus

Reason it remains an alternate rather than the current default:

- stronger display and LVGL path
- more processing margin for richer UI
- but changes the controller family, power profile, and software baseline more than necessary

Current stance:

- if the project later prioritizes a richer UI above all else, ESP32S3 Plus is the best alternate
- for now, nRF52840 Plus is the least disruptive and most coherent evolution of the original controller choice

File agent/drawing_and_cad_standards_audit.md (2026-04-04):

# Drawing And CAD Standards Audit

Date: 2026-04-02

## Audit basis

- `.github/references/professional-drawing-and-cad-standards.md`
- `.github/skills/reference-svg-maintenance/`
- `.github/skills/pcbway-rfq/`
- `agent/pcbway_handoff.md`

## Current pass items

- All five SVG reference sheets now declare units in mm, not-to-scale status, source-of-truth geometry, and reference-only status.
- The SVG workflow now enforces section naming, grayscale-readable meaning, title gutters, panel alignment, note-box capacity, and XML validation.
- The PCBWay RFQ workflow now treats ambiguity-reduction documents as top-priority package items when requested.
- The prototype RFQ package correctly treats STL geometry, manifest, and written notes as the primary quote package, with SVGs only as supplemental reference sheets.
- The repo now distinguishes clearly between reference SVGs and formal manufacturing drawings.

## Remaining controlled gap

- The repo does not yet contain the final formal 2D release drawing for the hybrid wet-part set.
- That is acceptable at the current project stage because the hose-plug fit validation gate is still open.
- Final production-release compliance is not complete until the frozen wet-part geometry has a formal mechanical drawing package.

## Practical conclusion

- Current reference-diagram practice is aligned with professional global drafting expectations for non-release support sheets.
- Current prototype RFQ practice is aligned with a professional quote package for fit-only printed parts.
- The final hybrid wet-part release remains intentionally gated on validation and a later formal drawing package.

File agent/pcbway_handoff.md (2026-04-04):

# PCBWay Handoff Strategy

This file is written as a practical manufacturing guide for using PCBWay as the primary fabrication partner.

## Manufacturing phases

The project should be split into three separate procurement tracks.

### Track 1: low-cost plastic geometry prototype

Purpose:

- verify size
- verify hose fit
- verify clamp access
- verify cabinet or installation envelope
- verify assembly order

This part is not meant to validate:

- final thermal performance
- long-term sealing
- final surface finish quality

What to send:

- STEP or STL exported from the SCAD model
- clear note that this is a fit prototype only
- request that the three hose-plug size options ship in the same order

Preferred request notes:

- prefer PLA for the first quote because cost matters more than final material similarity
- prioritize dimensional fidelity over cosmetic finish
- keep the three hose-plug ODs accurate
- do not resize or smooth the hose-plug outside profiles or trapped root geometry without approval

If PLA process selection becomes awkward:

- ABS is acceptable
- another rigid prototype plastic is acceptable for fit-only work, but document the substitution

## Track 2: Final hybrid wet block

Default materials:

- lid: 316L stainless steel
- base: CNC POM
- separate hose plugs: CNC POM

What to send:

- separate STEP models for the lid, base, and hose plugs
- 2D drawing or PDF with explicit dimensions and callouts
- notes for flatness, finish, seal groove, hose-plug interlock, and leak test

Critical callouts for the quote package:

- no internal bore reduction below 14.5 mm
- keep the 6 straight-channel geometry in the lid
- preserve the 28 mm smooth transition sections
- POM base and hose plugs must be CNC machined from solid stock, not printed
- wet surfaces must be deburred
- TEC landing face in the lid must be flat and smooth
- O-ring groove in the base must be clean and burr-free
- use through-bolts and compression control; do not silently convert the POM base to tapped screw retention
- part must be leak tested before shipment

Preferred added notes:

- passivate 316L after machining if available
- do not abrasive-blast inside wet passages
- hand polish or otherwise smooth the diffuser / converger surfaces if tool marks are heavy
- send photos of the landing face, groove, and hose plugs before shipping if possible

If the final hose-plug OD is not frozen yet:

- do not release the final hybrid wet-part order until the plastic hose-plug options are tested on the real Fluval hose

## Track 3: XIAO carrier PCB and PCB assembly

This should be treated as a separate RFQ from the mechanical work.

Recommended board purpose in rev 1:

- mount the XIAO nRF52840 Plus module
- preserve or replicate the XIAO pin-row geometry needed by the Round Display
- distribute regulated power for logic and sensors
- break out connectors
- condition control signals to the external TEC driver
- support sensing, alarms, and debugging

Recommended rev 1 non-goal:

- do not integrate the full 24 V 6 A TEC power stage onto the same first-pass controller board

## PCBWay PCB / PCBA file requirements to prepare

PCBWay calls out these core PCBA files:

- BOM in CSV, XLS, or XLSX
- Gerber files, including at minimum the copper, silkscreen, and solder paste layers in RS-274X format
- centroid / pick-and-place / XY rotation file

PCBWay also explicitly recommends sending additional documents even when not mandatory:

- assembly drawings
- special assembly instructions
- images or photos if something about placement or orientation could be ambiguous

That recommendation matters here because the XIAO module, antenna keepout, and external-wiring intent should all be documented clearly.

Because the project now uses the Round Display as the HMI:

- the assembly drawing should explicitly show the display mating orientation
- the pin budget and the use of Plus-only additional pads should be called out clearly
- if the Round Display is not being sourced by PCBWay, note whether it is customer-assembled later or whether the interface board is being quoted separately from the HMI module

## Suggested controller-board manufacturing spec

Recommended baseline:

- 4-layer FR-4
- 1.6 mm thickness
- ENIG finish
- ordinary logic-grade copper is sufficient if TEC current stays off-board in rev 1

PCB capability references that matter from PCBWay:

- standard boards up to 14 layers
- FR-4, aluminum, and copper-base board options exist
- typical outline tolerance around +/-0.2 mm for CNC-routed boards
- standard minimum trace and spacing around 0.1 mm / 4 mil
- castellated-hole capability exists in their advanced capability references

Design implication:

- a XIAO-carrier board using castellated module mounting is reasonable
- keep the design comfortably within standard capabilities rather than pushing minimum limits

## Questions to explicitly send PCBWay before the PCBA order

1. Can PCBWay source the exact Seeed Studio XIAO nRF52840 Plus module, or should it be consigned by the customer?
2. If consigned, do they prefer the XIAO as a customer-supplied SMT module in tape / tray or as loose modules?
3. Do they want any special stencil or placement note for the castellated module footprint?
4. Can they assemble the XIAO directly to the interface board, or do they prefer headers for prototype stage?
5. If the Round Display is included in the controller stack, do they want that module assembled separately from the main interface board or left as a customer-installed accessory?

Current engineering recommendation:

- prefer direct board mounting of the XIAO as a module
- fall back to manual module installation only if sourcing or assembly becomes awkward

## Data package quality level

Because the project is intentionally over-engineered for prototype quality, the RFQ package should include more than the bare minimum.

For mechanical RFQs include:

- 3D CAD
- 2D drawing
- finish notes
- sealing notes
- leak test note
- material note
- critical-to-function dimensions highlighted
- units in mm and clear drawing status or revision
- explicit statement that any supplemental SVG is reference-only and not a substitute for the release drawing
- explicit approval requirement before any manufacturability-driven geometry change

For PCBA RFQs include:

- BOM
- Gerbers
- centroid file
- assembly drawing
- special assembly instructions when orientation or source responsibility could be ambiguous
- marked images or photos when a module stack-up or cable orientation could be misread
- notes for antenna keepout
- notes for any customer-supplied XIAO module
- explicit statement that high current stays off-board in rev 1

## Recommended contact discipline

Do not rely on the instant quote form alone when something is critical.

When the part is close to being ordered:

- send a short message to the assigned sales rep
- restate the critical no-restriction bore requirement
- restate the wet-surface finish and leak-test requirement
- ask for confirmation that there are no manufacturability changes without approval

This is especially important for the final hybrid wet part because silent geometry changes inside the water path would defeat the design intent.

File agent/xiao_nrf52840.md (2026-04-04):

# Seeed Studio XIAO nRF52840 And nRF52840 Plus Notes

This file summarizes the XIAO nRF52840 family technical details that matter to this project, with emphasis on why the project baseline moved to the Plus variant.

## Why this module family fits the project

The Seeed Studio XIAO nRF52840 family is a good match because it combines:

- very small footprint
- onboard BLE capability
- enough GPIO and serial interfaces for sensors and control
- an SMT-friendly module form factor that can be mounted on a custom carrier PCB

The project baseline is now the XIAO nRF52840 Plus rather than the standard XIAO nRF52840.

## Core technical details

Module:

- standard product: Seeed Studio XIAO nRF52840
- standard Seeed SKU: 102010448
- project baseline product: Seeed Studio XIAO nRF52840 Plus
- project baseline Seeed SKU: 102010672
- dimensions: 21 x 17.8 mm
- form factor: XIAO family castellated / SMT-friendly module

MCU:

- Nordic nRF52840
- ARM Cortex-M4F
- 64 MHz

Memory:

- on-chip: 1 MB flash, 256 KB RAM
- onboard external flash: 2 MB QSPI flash

Wireless:

- Bluetooth Low Energy 5.4
- Bluetooth Mesh support
- NFC support
- onboard antenna

Power and electrical:

- logic level: 3.3 V I/O only
- typical operating rail: 3.3 V
- Type-C / VBUS input: 5 V
- battery input support: 3.7 V nominal Li-ion / LiPo
- onboard charger IC: BQ25101 family behavior referenced by Seeed resources
- selectable charging current: 50 mA or 100 mA
- standby power consumption: about 5 uA class according to Seeed material

Interfaces called out by Seeed for the base XIAO nRF52840:

- 1 x UART
- 1 x I2C
- 1 x SPI
- 1 x NFC
- 1 x SWD
- 11 GPIO with PWM capability
- 6 ADC-capable inputs

Additional Plus-variant notes from Seeed:

- about 9 additional SMD or castellation GPIO beyond the standard XIAO header set
- around 20 PWM-capable GPIO total in the Plus family description
- extra interfaces exposed compared with the base board, including additional serial resources
- same classic 21 x 17.8 mm XIAO footprint, but with expanded backside pad access

Other onboard items:

- reset button
- RGB user LED
- charge/status LED

## Project implications

### Strong positives

1. Wireless telemetry and configuration are available without adding another radio.
2. The module is small enough to place on a compact controller board.
3. The module already exists as an SMT-friendly production part, which is helpful for PCBWay assembly.
4. Seeed provides schematics, KiCad project files, footprints, symbol libraries, dimension drawings, and bottom-pad data.

### Constraints that matter here

1. All user I/O should be treated as 3.3 V only.
2. The onboard antenna needs a real keepout strategy.
3. The board should not be buried next to the stainless block or CPU cooler if BLE range matters.
4. The first rev should use the XIAO as a module on a carrier or interface board, not as a loose dev board on wiring.
5. If the Round Display is used, the standard header pins are heavily consumed, so the Plus-only additional pads become the practical system I/O reserve.

## Suggested PCB design rules around the XIAO

For a custom carrier board to be assembled by PCBWay:

- place the XIAO at a board edge so the antenna end faces outward
- avoid copper pour, ground pour, or tall metal near the antenna end of the module
- avoid standoffs, shields, or the PSU directly beside the antenna
- keep USB access possible, or provide a clear programming strategy through pads or fixture access
- add SWD pads for recovery and low-level debugging
- use Seeed's official footprint and bottom-pad data rather than measuring from product photos
- if using the Plus variant, route the extra backside pads intentionally; they are the reason to use the Plus variant at all

## Round Display compatibility note

The Round Display is a strong HMI option for this project, but it changes the pin budget dramatically.

Important points:

- hardware fit is aligned with the classic XIAO form factor
- on the nRF52840 family, the display path is safer through Arduino GFX or Seeed_GFX than through the TFT-only examples
- using the Plus variant solves the I/O shortage created by the display, but only if the custom PCB actually exposes the extra Plus pads

## Practical notes from Seeed documentation

- Seeed calls out two Arduino board-package options with different tradeoffs
- BLE / low-energy focused work is typically associated with the Seeed nRF52 boards package
- some Seeed package combinations may need `Adafruit_TinyUSB` for reliable Serial behavior
- the module supports Arduino, CircuitPython, and MicroPython

## Project-specific recommendation

Use the XIAO Plus on an interface or interposer PCB that provides:

- regulated power input
- connectorized sensors
- driver interface conditioning
- alarm outputs
- test pads

Prefer this over the standard XIAO nRF52840 when the Round Display is part of the system.

Avoid trying to integrate the full TEC power stage onto the same first-pass XIAO carrier board.

## Useful resources to pull later if needed

Seeed exposes resources for the XIAO family including:

- schematic PDF
- KiCad project files
- XIAO footprints and symbols
- dimension DXF
- bottom-pad positioning data

Those resources should be used when the custom carrier PCB is actually drafted.

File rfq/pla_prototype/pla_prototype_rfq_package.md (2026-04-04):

# PCBWay PLA Fit Prototype RFQ Package

This package is for the first low-cost PLA fit and geometry prototype of the inline cold block, its interchangeable hose-plug options, and its open prototype support frame.

Status:

- current prototype print-quote package
- all stated dimensions are in mm
- any preview SVG sent with this package is reference-only and not to scale

## Directory note

- the prototype package now lives in `rfq/pla_prototype`
- this quote round should be sent as PLA

## Purpose

This order is only for:

- geometry validation
- hose-fit validation
- installation envelope validation
- screw and clamp access validation
- support-frame packaging validation for the cooler, PSU, and side HMI

This order is not intended to validate:

- final leak performance
- final thermal performance
- final material choice
- final long-term sealing reliability

## Parts to include in the first order

### Required core parts

### Part A: bundled lid-and-base print set

- quantity: 1 STL file containing the cold block lid and base
- source geometry: `tec_cold_block_mockup.scad`
- export mode: `part = "prototype_lid_base_bundle"`
- included contents: 1 cold block base and 1 cold block lid
- print layout: parts packed side-by-side with the broad flat outer faces on the build plane
- release intent: keep the two block halves together in one uploadable STL for the first quote round

### Part B: bundled hose-plug print set

- quantity: 1 STL file containing all six prototype hose plugs
- source geometry: `tec_cold_block_mockup.scad`
- export mode: `part = "prototype_hose_bundle"`
- included contents: 2 hose plugs at 16.0 mm OD, 2 hose plugs at 15.4 mm OD, and 2 hose plugs at 14.8 mm OD
- release intent: keep all hose-fit options together in one uploadable STL for the first quote round

### Optional convenience export: combined hose-lid-base print set

- quantity: 1 STL file containing Part A plus Part B in one tightly packed print layout
- source geometry: `tec_cold_block_mockup.scad`
- export mode: `part = "prototype_hose_lid_base_bundle"`
- included contents: 1 cold block base with the flat outer face down, 1 cold block lid with the flat outer face down, and all six prototype hose plugs standing upright with the hose ends up
- release intent: keep a single-print or single-upload convenience bundle available without changing the default RFQ split

### Part C: open prototype support frame

- quantity: 1
- source geometry: `tec_cold_block_mockup.scad`
- export mode: `part = "prototype_support"`
- intent: hold the block in a cradle, present the Round Display on the side with the XIAO mounted below the display, and provide an interlocking support kit with split rear PSU uprights, a center driver spine, a shallow upper shelf for the external driver keyed only into the spine, and a lower tie-slot landing on that spine for the external 24 V to 5 V logic buck
- assembly aids: hidden matching interface letters and light snap detents are built into the printed joints so the support kit can be dry-fit and glued without leaving visible assembly marks on the finished prototype
- release intent: include this in the first prototype order because fit and size validation now covers the full prototype assembly envelope

## Current geometry baseline

Cold block body excluding hose plugs:

- 140 x 92 x 24 mm

Split:

- lid: 8 mm
- base: 16 mm

Internal design intent:

- 6 straight channels
- each channel about 8.67 x 56 x 6 mm
- 5 internal fins at 2 mm, with no dedicated side walls
- cavity envelope 112 x 62 x 6 mm
- minimum bore target 14.5 mm
- smooth 28 mm inlet and outlet transitions
- 4 x Intel LGA1700 / LGA1851 hot-side mounting holes, 78 x 78 mm square, 4.3 mm clearance

Hose-plug options:

- installed main hose-plug OD: 16.0 mm
- extra hose-plug options: 15.4 mm and 14.8 mm
- hose-plug projection from block face: 24 mm
- trapped plug root is shared by all three ODs so the outside hose size can change without changing the lid or base

Prototype support frame:

- overall support footprint: about 248 x 190 mm
- packed support export footprint: about 282.9 x 240 x 8 mm
- open ladder-style cradle panel under the 140 x 92 block body
- cradle height: 8 mm
- side display mast: 62 mm wide, 116 mm tall overall, with a 34 mm screen window, controller slots relocated below the display, and universal Round Display mounting slots
- rear PSU support: full-width rear deck with two fixed-hole PSU uprights instead of a full solid wall
- upper driver shelf above the PSU position for the external TEC driver module, keyed into a narrow center spine without separate rear-deck brace legs, plus a lower tie-slot landing on the same spine for a compact external 24 V to 5 V logic buck below the driver
- low hose strain-relief tabs tucked close to both hose-plug positions and aligned with the bead position

## Requested material and process

Preferred:

- PLA using the lowest-cost 3D printing process that keeps dimensions accurate enough for fit checks

Fallback:

- another rigid prototype plastic is acceptable for fit-only work if PLA quoting is awkward, but quote PLA first

Priority:

- dimensional fidelity over cosmetic appearance
- lowest practical price over cosmetic appearance or wet-service finish

## Critical RFQ notes

1. Do not resize or smooth the hose-plug geometry or plug pockets without approval.
2. Keep the three hose-plug ODs accurate across both copies of each plug size in the hose bundle.
3. Preserve the overall body dimensions, current 6-screw assembly layout, and the trapped plug-pocket geometry.
4. Preserve the Intel LGA1700 / LGA1851 hot-side mounting-hole pattern.
5. This is a fit prototype only; cosmetic finish is secondary.
6. The parts do not need wet-service finish quality.
7. Keep the lid/base bundle and the hose bundle as separate multi-part uploads unless you first ask for approval to split them differently.
8. Preserve the interlocking support-kit geometry, the fixed Mean Well side-mount hole pair, the center driver spine, and the spine-keyed driver shelf if Part C is quoted; do not merge the rear structure back into a solid wall or crowd the hose exits.
9. If the support kit materially increases price, quote it separately rather than silently deleting or simplifying it.

## Files available now

- `C:\Users\reice\tec_cold_block\tec_cold_block_mockup.scad`
- `C:\Users\reice\tec_cold_block\whole_block_preview.svg`
- `C:\Users\reice\tec_cold_block\cold_block_lid_preview.svg`
- `C:\Users\reice\tec_cold_block\cold_block_base_preview.svg`
- `C:\Users\reice\tec_cold_block\hose_fit_coupons_preview.svg`
- `C:\Users\reice\tec_cold_block\cold_block_combined_preview.svg`
- `C:\Users\reice\tec_cold_block\fabrication_notes.md`
- `C:\Users\reice\tec_cold_block\rfq\pla_prototype\stl\prototype_lid_base_bundle.stl`
- `C:\Users\reice\tec_cold_block\rfq\pla_prototype\stl\prototype_hose_bundle.stl`
- `C:\Users\reice\tec_cold_block\rfq\pla_prototype\stl\prototype_hose_lid_base_bundle.stl`
- `C:\Users\reice\tec_cold_block\rfq\pla_prototype\stl\prototype_support_frame.stl`
- `C:\Users\reice\tec_cold_block\rfq\pla_prototype\parts_manifest.csv`

## Export status

OpenSCAD export is now working from this repo.

What this means:

- the RFQ package text is ready
- the SCAD source is ready
- the primary upload STL set is generated in `rfq/pla_prototype/stl`
- the top-level STL folder now contains the three core RFQ files plus `prototype_hose_lid_base_bundle.stl` as an additional convenience bundle
- VS Code has a reusable task named `Export OpenSCAD Prototype STL Set`
- the export task was run successfully on 2026-04-04 to regenerate the current STL set
- wrapper entrypoints exist in `rfq/pla_prototype/exports` so the exports do not rely on fragile `-D` string overrides

## Suggested upload plan

1. Upload `prototype_lid_base_bundle.stl`, `prototype_hose_bundle.stl`, `prototype_support_frame.stl`, `parts_manifest.csv`, and `pla_quote_message.txt` from this folder.
2. Ask for the lid/base bundle, the hose bundle, and the support-frame file in the first quote so the entire fitting and size envelope is validated together.
3. Do not rely on the preview SVGs unless a PCBWay rep asks for them; the STL files and written notes are the primary quote package, and any shared SVG should be labeled as a reference-only, not-to-scale supplement.
4. If a fresh export is needed later, run the VS Code task `Export OpenSCAD Prototype STL Set`.

## Acceptance criteria for the received prototype parts

Must verify:

- hose-fit behavior on all three hose-plug options
- plug-root seating and lid/base pocket alignment
- insertion depth and clamp access
- block body fits intended space
- lid and base align correctly
- screw holes and general proportions are correct enough to freeze the final hybrid geometry later
- the cooler / PSU / screen support footprint is stable enough before any powered bench work
- the display mast is readable from the chosen side and clear of the cooler envelope
- the fixed Mean Well PSU side-mount holes and upper driver shelf are serviceable with real hardware

## Next release after this RFQ

After testing of the PLA hose-plug parts:

- freeze the final hose-plug OD
- freeze any envelope adjustment
- prepare the final hybrid CNC machining package

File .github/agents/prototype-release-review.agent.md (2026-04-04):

---
name: "Prototype Release Review"
description: "Use for prototype/manufacturing readiness reviews, industrial-design coherence checks, vendor handoff audits, multi-part print-layout checks, file-alignment checks across SCAD/SVG/RFQ/exports, and go/no-go release verdicts."
tools: [read, edit, search, execute, todo]
user-invocable: true
---

You are the release-review specialist for this aquarium TEC project.

## Scope

- review whether a package is ready to send for a PLA fit prototype quote, hybrid CNC wet-part quote, controller PCB/PCBA quote, or a broader repo release sanity pass
- think like an industrial designer as well as a manufacturing reviewer: assembly clarity, service access, physical coherence, and vendor legibility matter alongside pure geometry correctness
- catch drift between source geometry, exports, manifests, quote notes, reference SVGs, and validation gates before a supplier sees the package

## Constraints

- do not approve a final hybrid wet-part release while the hose-plug OD is still unfrozen on the real hose
- do not treat preview SVGs as formal manufacturing drawings
- do not approve a final wet-part package that claims release readiness without source CAD, a neutral interchange model, and a formal 2D drawing or PDF
- do not allow part names, quantities, materials, or release status to drift across manifests, messages, package notes, and exported files
- do not relax the low-restriction 6-channel, 14.5 mm minimum-bore baseline without evidence
- do not silently remove support-frame content from the PLA prototype package when the review scope includes full assembly-envelope validation
- do not treat scattered multi-part print bundles or support-heavy orientations as acceptable when a tighter support-light layout is available
- do not accept exposed assembly letters on finished-facing support parts or glue-only interlocking joints when hidden witness labels and light PLA detents would make the kit clearer to assemble

## Approach

1. Read the relevant `agent/` files first, especially `agent/agent.md`, `agent/pcbway_handoff.md`, and `agent/validation_and_open_items.md`.
2. Read the shared professional drawing/CAD standard and the package files for the scope being reviewed.
3. Compare the source-of-truth geometry, export wrappers, generated outputs, manifests, quote message text, preview SVGs, multi-part print orientations, packing efficiency, and open validation gates.
4. Review the package like an industrial designer: check whether the part family reads coherently, assembly order is understandable, clamp and service access are believable, human-facing components are positioned intentionally, and visuals communicate intent without supplier guesswork.
5. For interlocking printed kits, check that joint cues are mirrored and hidden after seating, and that any detents are small enough to aid dry-fit alignment without becoming brittle snap hooks.
6. Separate blockers from polish. Fix in-repo drift directly when safe; if a blocker depends on physical validation or missing external data, keep it open explicitly.
7. End with a direct verdict: ready to send, quote-ready but not final-release ready, or not ready.

## Output

- a concise go/no-go verdict with blockers called out first
- concrete file updates when the package can be tightened in-repo
- a short list of residual vendor-facing risks when a package is intentionally sent before the full release gate is closed

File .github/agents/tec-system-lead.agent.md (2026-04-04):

---
name: "TEC System Lead"
description: "Use for system architecture, cross-discipline tradeoffs, BOM alignment, controller baseline decisions, PCBWay package planning, and deciding whether project memory is safe to remove."
tools: [read, edit, search, execute, todo]
user-invocable: true
---

You are the systems lead for this aquarium TEC chiller project.

## Scope

- own cross-discipline decisions spanning thermal, hydraulic, electrical, controls, and manufacturing
- keep the repo aligned when files drift out of sync
- decide whether documents are redundant enough to delete safely

## Constraints

- do not relax the low-restriction hydraulic baseline without evidence
- do not move the TEC high-current path onto the rev-1 controller board by default
- do not delete the `agent/` folder unless every unique engineering detail has been migrated elsewhere
- when changing prototype print conventions, keep the agents, skills, repo memory, docs, and SCAD export helpers aligned in the same pass

## Approach

1. Read the relevant `agent/` files first.
2. Compare current docs, instructions, and package files before changing or deleting anything.
3. Restore or update the smallest set of files needed to keep the repo coherent.
4. When a project convention changes materially, update the relevant agents, skills, and repo memory in the same pass.
5. When drawings or CAD release docs change, enforce the shared professional drawing/CAD standard and prioritize explicit PCBWay documentation guidance over convenience.
6. Leave clear, manufacturing-usable outputs.

## Output

- concise verdicts
- concrete file changes
- explicit risks or unresolved assumptions

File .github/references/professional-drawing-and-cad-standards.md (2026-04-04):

# Professional Drawing And CAD Standards

This repo uses a practical global engineering-document baseline drawn from common ISO and ASME practice.

- ISO-style drawing discipline: representation, dimension clarity, sheet layout, projection awareness, scale discipline, and title-block metadata
- ASME Y14-style product-definition discipline: engineering drawing practice, tolerancing discipline, and digital-product-definition separation between reference graphics and release drawings

## Priority Order

1. Explicit PCBWay requirements or ambiguity-reduction recommendations
2. Functional manufacturability and inspection needs
3. Repo-specific SCAD ownership, layout, and palette conventions

## Reference Diagram Baseline

- Every reference SVG must declare its title, units in mm, scale status as not to scale unless a controlled scale is intentional, source-of-truth model, and reference-only status.
- Named views and section cuts must be explicit and consistent across related sheets.
- Line hierarchy must stay consistent: outlines, hidden geometry, centerlines, dimensions, and overlays must remain visually distinct.
- Color may support meaning, but meaning must still be readable without color through geometry, labels, captions, and line style.
- Prefer short feature callouts with leader lines over free-floating prose near geometry.
- Reserve full-sentence explanation for note boxes or note bands, and visually separate those note areas from geometry with a divider or clear gutter.
- Remove duplicate or repeated labels once a formal callout is present.
- Notes belong beside the geometry, not on top of the geometry.
- Dimensions on reference SVGs should aid interpretation and must not create conflicting or duplicate manufacturing intent.
- If a sheet starts needing full release metadata, inspection dimensions, or tolerance control, move that content into a proper manufacturing drawing instead of overloading the preview SVG.

## Manufacturing Drawing And CAD Release Baseline

- Keep one geometry source of truth and export from that source consistently.
- For mechanical release, provide source CAD, a neutral interchange format such as STEP, and a 2D drawing or PDF.
- Use a clear release identity: part or assembly name, revision or status, units, scale or not-to-scale statement, and material.
- State finish, post-process, and any critical special requirements explicitly.
- Use general tolerances or explicit critical tolerances deliberately; do not scatter ambiguous precision across the drawing.
- Use datums and GD&T only where they materially improve manufacturability or inspection clarity.
- Avoid duplicate, chained, or conflicting dimensions that obscure inspection intent.
- Call out holes, grooves, sealing features, and critical interfaces explicitly.
- Highlight dimensions that are critical to fit, flow, sealing, or assembly.
- Make it explicit that manufacturability-driven changes require approval before the supplier alters geometry.
- If orientation, assembly order, or customer-supplied content could be misread, add assembly drawings, marked images, or photos.

## PCBWay Priority Rules

- Treat PCBWay requests for assembly drawings, special instructions, images, or photos as required deliverables, not optional extras.
- For fit-only prints, prioritize dimensional fidelity over cosmetic finish.
- For production mechanical work, do not rely on STL or informal reference graphics when a STEP model and formal 2D drawing are warranted.
- Keep units in mm across the package unless a supplier explicitly requires otherwise.
- Ask for confirmation that no manufacturability changes, geometry simplifications, or substituted assumptions will be made without approval.

## Repo Interpretation

- The SVG preview sheets in this repo are reference diagrams, not release drawings.
- The final stainless wet-part release still requires a formal mechanical drawing package once the geometry is frozen.
- Supplemental SVGs may accompany a quote or review package, but they must be labeled as reference-only and must not replace the release drawing.

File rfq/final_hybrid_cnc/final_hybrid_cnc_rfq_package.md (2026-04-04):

# PCBWay Final Hybrid CNC RFQ Package

This folder is the quote package for the hybrid wet-part direction using a 316L lid, CNC POM base, and CNC POM hose plugs.

Status:

- preliminary hybrid CNC quote package
- all stated dimensions are in mm
- preview SVGs are reference-only and not to scale
- final release order remains gated on real-hose validation of the three hose-plug OD options

## Purpose

This package is for:

- preliminary CNC machining quote collection
- manufacturability review of the current lid and base geometry baseline before the final hose-plug OD and formal drawing are locked
- side-by-side pricing of the three alternate hose-plug OD pairs

This package is not yet the final production release because:

- the final hose-plug OD has not been frozen on the real hose
- the formal 2D manufacturing drawing is still pending

## Parts to quote

### Required fixed parts

### Part A: cold block lid

- quantity: 1
- material: 316L stainless steel
- source geometry: `tec_cold_block_mockup.scad`
- export wrapper: `rfq/final_hybrid_cnc/exports/export_lid.scad`

### Part B: cold block base

- quantity: 1
- material: CNC POM
- source geometry: `tec_cold_block_mockup.scad`
- export wrapper: `rfq/final_hybrid_cnc/exports/export_base.scad`

### Alternate hose-plug quote groups

### Part C: hose-plug pair, 16.0 mm OD

- quantity: 2
- material: CNC POM
- source geometry: `tec_cold_block_mockup.scad`
- export wrapper: `rfq/final_hybrid_cnc/exports/export_plug_main.scad`

### Part D: hose-plug pair, 15.4 mm OD

- quantity: 2
- material: CNC POM
- source geometry: `tec_cold_block_mockup.scad`
- export wrapper: `rfq/final_hybrid_cnc/exports/export_plug_mid.scad`

### Part E: hose-plug pair, 14.8 mm OD

- quantity: 2
- material: CNC POM
- source geometry: `tec_cold_block_mockup.scad`
- export wrapper: `rfq/final_hybrid_cnc/exports/export_plug_small.scad`

## Current geometry baseline

Cold block body excluding hose plugs:

- 140 x 92 x 24 mm

Split:

- lid: 8 mm
- base: 16 mm

Internal design intent:

- 6 straight channels in the lid
- each channel about 8.67 x 56 x 6 mm
- 5 internal fins at 2 mm
- cavity envelope 112 x 62 x 6 mm
- minimum bore target 14.5 mm end-to-end
- smooth 28 mm inlet and outlet transitions
- 4 x Intel LGA1700 / LGA1851 hot-side mounting holes on a 78 x 78 mm square

Hose-plug root geometry shared by all three OD options:

- hose-plug projection from block face: 24 mm
- flange: 22.0 OD x 2.0 thick
- neck: 16.8 OD x 4.0 long
- trapped head: 22 x 15 x 6 rounded profile
- throat: 17.0
- through bore: 14.5 minimum

## Requested material and process

Please quote:

- lid as CNC 316L stainless steel
- base as CNC POM machined from solid stock
- hose plugs as CNC POM machined from solid stock

## Critical RFQ notes

1. Preserve the 14.5 mm minimum bore through the hose plugs, throat, and block-owned passages.
2. Keep the 6 straight-channel geometry in the lid and preserve the 28 mm smooth transition sections.
3. Do not alter the trapped hose-plug root geometry or plug pockets without approval.
4. Do not introduce hidden flow restrictions, substitute fittings, or simplify the diffuser / converger without approval.
5. Deburr all wet surfaces.
6. Keep the TEC landing face in the lid flat and smooth.
7. Keep the O-ring groove in the base clean and burr-free.
8. Use through-bolts and compression control in the final stack; do not silently redesign the base for tapped-plastic-only clamp retention.
9. Leak test before shipment if available.
10. Any manufacturability-driven geometry change requires approval before cutting material.

## Files included or generated here

Primary quote files:

- `rfq/final_hybrid_cnc/parts_manifest.csv`
- `rfq/final_hybrid_cnc/cnc_quote_message.txt`
- `rfq/final_hybrid_cnc/step/cold_block_lid.step`
- `rfq/final_hybrid_cnc/step/cold_block_base.step`
- `rfq/final_hybrid_cnc/step/hose_plug_main_16_0mm.step`
- `rfq/final_hybrid_cnc/step/hose_plug_mid_15_4mm.step`
- `rfq/final_hybrid_cnc/step/hose_plug_small_14_8mm.step`

Supplemental support files:

- `rfq/final_hybrid_cnc/stl/*.stl`
- `rfq/final_hybrid_cnc/csg/*.csg`
- `whole_block_preview.svg`
- `cold_block_lid_preview.svg`
- `cold_block_base_preview.svg`
- `hose_fit_coupons_preview.svg`
- `cold_block_combined_preview.svg`

## Export status

- wrapper entrypoints exist in `rfq/final_hybrid_cnc/exports`
- `rfq/final_hybrid_cnc/export_hybrid_step_set.ps1` regenerates the STEP, CSG, and STL set
- `.vscode/tasks.json` includes a reusable task for the hybrid STEP export set

## Suggested upload plan

1. Upload the STEP files, `parts_manifest.csv`, and `cnc_quote_message.txt` for the first hybrid quote request.
2. Ask PCBWay to quote Part A and Part B as fixed parts and Parts C, D, and E as alternate hose-plug pair options.
3. Share the SVG reference sheets only if a PCBWay rep asks for additional visual clarification, and label them as reference-only supplements.
4. Do not place the final machining order until the real hose test selects one hose-plug OD.

## Next release after this RFQ

After the PLA hose-plug round selects the final OD:

- freeze the chosen hose-plug pair
- add the formal 2D manufacturing drawing
- release the final hybrid lid/base/plug machining package

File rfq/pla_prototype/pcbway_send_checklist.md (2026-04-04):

# PCBWay Prototype Send Checklist

Status date: 2026-04-03

Decision:

- ready to send for a PLA fit-only quote
- send the lid/base bundle STL, the hose bundle STL, and the support-frame STL in the first order
- include the support frame because full fit and size validation now covers the whole prototype envelope

## Scope and release gate

- [x] Fit-only purpose is stated clearly.
- [x] Final hybrid CNC release is still blocked until hose-plug testing is complete.
- [x] Prototype material is now documented as PLA-first for lowest cost.
- [x] Stated dimensions for the prototype package are treated as mm.

## Package completeness

- [x] Lid/base bundle is defined as a separate prototype STL.
- [x] Hose bundle is defined as a separate prototype STL with two copies of each hose-plug size.
- [x] Support frame is listed consistently as part of the required prototype set.
- [x] Parts manifest matches the three-file STL export set.
- [x] Quote message matches the package scope and material.
- [x] Quote message and package text require approval before geometry changes.
- [x] If supplemental SVGs are shared, they are documented as reference-only and not-to-scale.
- [x] Package wording is consistent with the current task/export naming and file set.
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

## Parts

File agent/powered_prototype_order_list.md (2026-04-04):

# Powered Prototype Order List

This file freezes the current buy list for the first powered prototype.

Current exact powered-prototype electrical baseline:

- external IBT-2 Double BTS7960 43 A H-bridge module
- external TOBSUN EA15-5V 24 V to 5 V 3 A 15 W buck mounted below the BTS7960 on the lower support-spine landing
- Thermalright Assassin X 120 Refined SE heatsink with the stock fan set aside and replaced by a Noctua NF-F12 industrialPPC-24V-2000 IP67 PWM fan so the prototype only needs 24 V and 5 V rails

Current layout and wiring assumptions:

- use the main 16.0 mm hose-plug option on both ports for the current dry prototype component sheet and wiring documentation
- leak sensor is included in the current dry-build prototype, not left as an optional add-on
- harness colors and target cut lengths are defined in `agent/powered_prototype_wiring_diagram.md`, and the powered-prototype 2D reference sheets are `powered_prototype_component_layout.svg` and `powered_prototype_electrical_block.svg`

## Order now: fabricated items

| Item | Qty | Exact model or identifier | Notes |
| --- | ----: | --- | --- |
| PLA prototype print set | 1 set | `prototype_lid_base_bundle.stl`, `prototype_hose_bundle.stl`, `prototype_support_frame.stl` | Order the full fit set together so the block, hose-plug options, and powered support geometry are validated in one round |
| Copper spreader | 1 | Custom C110 copper plate, 60 x 60 x 5 mm | Flat machined plate between TEC and cooler |

## Order now: exact bought parts

| Item | Qty | Exact model or identifier | Notes |
| --- | -----: | --- | --- |
| TEC module | 1 | TEC126306 / TEC1-26306, 50 x 50 mm, 24 V, 6 A nominal | Locked thermal baseline |
| Hot-side heatsink | 1 | Thermalright Assassin X 120 Refined SE | Use the heatsink and Intel mounting hardware; do not use the bundled 12 V fan in the current exact build |
| Hot-side fan | 1 | Noctua NF-F12 industrialPPC-24V-2000 IP67 PWM | Replaces the stock cooler fan and deletes the need for a 24 V to 12 V rail |
| Thermal paste | 1 | Noctua NT-H2, 10 g | Enough for TEC, spreader, and cooler interfaces plus rework |
| Main PSU | 1 | Mean Well LRS-350-24 | Locked project PSU |
| TEC driver | 1 | IBT-2 Double BTS7960 43 A H-bridge module, 50 x 50 mm board class | Matches the current support-driver reference envelope |
| Logic buck module | 1 | TOBSUN EA15-5V, 24 V to 5 V, 3 A, 15 W DC-DC converter | Mandatory 24 V to 5 V logic supply for the powered prototype; current support layout assumes this larger enclosed module on the lower support-spine landing |
| Main controller | 1 | Seeed Studio XIAO nRF52840 Plus, SKU 102010672 | Locked controller baseline |
| Local HMI | 1 | Seeed Studio Round Display for XIAO, SKU 104030087 | Locked local HMI baseline |
| Water temperature probe | 1 | Adafruit Waterproof DS18B20, PID 381 | Skip this purchase only if the stock probe already on hand is kept |
| Cold-block temperature sensor | 1 | Analog Devices DS18B20+ | Use TO-92 package on a short custom lead for bonded cold-side sensing |
| Hot-side temperature sensor | 1 | Analog Devices DS18B20+ | Use TO-92 package on a short custom lead near the cooler base or heat-pipe root |
| Intake-air temperature sensor | 1 | Analog Devices DS18B20+ | Use TO-92 package on a light lead support upstream of the fan |
| Outlet-air temperature sensor | 1 | Analog Devices DS18B20+ | Use TO-92 package on a light lead support in the exhaust gap |
| Humidity sensor | 1 | Adafruit SHT31-D Temperature and Humidity Sensor Breakout, PID 2857 | Current exact condensation-monitor choice |
| Leak sensor | 1 | DFRobot Gravity Water Sensor, SEN0205 | Included exact prototype leak sensor; wire it as the current thresholded leak-input path in the dry-build harness |
| Local alarm | 1 | Mallory Sonalert PS-580Q | 5 V buzzer for local failsafe indication |
| Driver interface buffer | 1 | Texas Instruments SN74AHCT125PW | Treat as standard with the generic BTS7960 module |
| TEC branch fuse | 1 | Bussmann ATM-10 | Place near the PSU branch point |
| Logic branch fuse | 1 | Bussmann ATM-2 | Protect the Pololu buck and logic branch |
| TEC wiring |  1 lot | BNTECHGO 16 AWG silicone wire, red and black | Keep TEC and driver runs short |
| General logic wiring |  1 lot | Alpha Wire 3050, 24 AWG stranded hookup wire | Logic, alarm, and low-current control runs |
| Temperature harness wire |  1 lot | Belden 9533, 24 AWG 3-conductor | Shared 1-Wire trunk plus serviceable probe branches |
| J1 connector set |  1 set | JST B2P-VH(LF)(SN), VHR-2N, SVH-21T-P1.1 | 24 V auxiliary input connector family |
| J3 and J5 connector sets | 2 sets | JST B3B-PH-K-S(LF)(SN), PHR-3, SPH-002T-P0.5S | Shared temperature bus and leak-sensor connector family |
| J4 connector set |  1 set | JST B4B-PH-K-S(LF)(SN), PHR-4, SPH-002T-P0.5S | Humidity or auxiliary I2C connector family |
| J2 connector set |  1 set | JST B5B-XH-A(LF)(SN), XHP-5, SXH-001T-P0.6 | External TEC-driver control connector family |
| SWD cable | 1 | Tag-Connect TC2030-IDC-NL | Current exact debug-programming cable choice |
| Insulation foam |  1 lot | Armacell AP ArmaFlex self-adhesive sheet, 6 mm | Default block and first-tube insulation thickness |
| Small cable ties | 1 pack | HellermannTyton T18R | Use for the lower buck mount and harness dressing |
| Sensor bond adhesive | 1 | MG Chemicals 8329TCM-6ML | For hot-side and cold-block sensor attachment |
| Sensor restraint tape | 1 roll | 3M 1181 copper foil tape, 1/4 in width | Supplemental probe restraint and strain relief |
| Block screws | 6 | M3 x 30 mm A2-70 stainless socket-head cap screws | Current exact prototype through-bolt choice |
| Block nuts | 6 | M3 A2 nylon-insert locknuts | Use with the through-bolts |
| Block washers | 12 | M3 stainless flat washers | One washer under each head and nut |
| Compression sleeves / hard stops | 6 | 316 stainless spacer, 3.2 mm ID x 4.0 mm OD x 24 mm long | Buy off the shelf if available or cut from spacer stock |

## Order after one measurement or hardware check

| Item | Qty | Trigger | Exact family or identifier | Notes |
| --- | ---: | --- | --- | --- |
| Tubing clamps | 4 to 6 | After real hose and plug fit are checked | Oetiker 167-series 304 stainless stepless ear clamps | Freeze the exact clamp size only after the chosen hose-plug OD is validated on the real Fluval hose |
| Final seal cord | 1 length | After groove measurement on the released wet part | EPDM 70 A, 2.0 mm round cord | Cut length should come from the released groove, not the nominal SCAD perimeter |

## Do not order yet

| Item | Reason |
| --- | --- |
| Final 316L lid, CNC POM base, and CNC POM hose plugs | Wait until hose-plug fit and Gate 1 geometry validation are complete |
| Custom controller interface board | Not yet captured as a finished schematic, PCB layout, and PCBA package |
| Final gasket or joined seal quantity | Freeze after the hybrid wet-part geometry and groove dimensions are released |

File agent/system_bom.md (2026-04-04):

# System BOM

This is the working project BOM. It includes locked parts, recommended parts, and provisional placeholders that still need final selection.

Status legend:

- Locked: considered the current baseline
- Preferred: recommended but still replaceable
- Provisional: best current choice, not frozen
- TBD: exact part not yet frozen

## Thermal and mechanical

| Item | Qty | Status | Recommended part / spec | Notes |
| --- | -----: | --- | --- | --- |
| TEC module | 1 | Locked | TEC126306 / TEC1-26306, 50 x 50 mm, 24 V, 6 A nominal | Electrical input ceiling about 144 W |
| Hot-side cooler | 1 | Locked | Thermalright Assassin X 120 Refined SE | Current exact heatsink choice for Intel LGA1700 / LGA1851 |
| Hot-side fan, prototype | 1 | Preferred | Noctua NF-F12 industrialPPC-24V-2000 IP67 PWM | Replaces the stock cooler fan in the current exact prototype order so the powered build stays on 24 V and 5 V rails only |
| Copper spreader | 1 | Locked | C110 or OFHC copper, 60 x 60 x 5 mm | Between TEC and CPU cooler |
| Thermal paste | 1 | Preferred | Noctua NT-H2, 10 g | Use between all metal/TEC interfaces |
| Cold block, fit mockup |  1 set | Locked | 3D printed PLA fit prototype; ABS or other rigid plastic acceptable if PLA quoting is awkward | Geometry validation only |
| Prototype support kit | 1 | Preferred | Interlocking plastic support kit, about 248 x 190 mm assembled overall | Cradles the block, carries side HMI, uses split PSU uprights plus a center driver spine and a spine-keyed shelf, and can be quoted separately to keep the core fit round cheap |
| Cold block lid, final | 1 | Locked | CNC 316L stainless steel | Thermal landing, channel pack, and upper wet path |
| Cold block base, final | 1 | Locked | CNC POM | Lower wet path, O-ring groove, and hybrid base |
| Hose plugs, final | 2 | Locked | CNC POM | Separate replaceable hose plugs; final OD follows prototype hose-plug fit result |
| O-ring or seal cord | 1 | Provisional | EPDM 70A round cord, 2.0 mm cross section | Final cut length should follow the released groove dimension, not the nominal SCAD perimeter |
| Block assembly screws | 6 | Preferred | M3 x 30 mm A2-70 stainless socket-head cap screws | Current exact prototype through-bolt choice; use with washers and locknuts |
| Compression sleeves / hard stops | 6 | Preferred | 316 stainless spacer, 3.2 mm ID x 4.0 mm OD x 24 mm long | Current exact prototype hard-stop target; custom cut is acceptable |
| Insulation foam |  1 lot | Preferred | Armacell AP ArmaFlex self-adhesive sheet, 6 mm | Current default insulation thickness for block and first tubing sections |
| Tubing clamps | 4 to 6 | Preferred | Oetiker 167-series 304 stainless ear clamps | Freeze exact size only after hose-plug validation on the real hose |

## Power and drive

| Item | Qty | Status | Recommended part / spec | Notes |
| --- | ----: | --- | --- | --- |
| Main PSU | 1 | Locked | Mean Well LRS-350-24, 24 V, 14.6 A, 350.4 W | Approved baseline supply |
| TEC driver, prototype | 1 | Locked | IBT-2 Double BTS7960 43 A H-bridge module | Approved first powered-prototype driver; keep the received board in the 50 x 50 mm class that matches the current support reference |
| TEC driver, quality-upgrade path | 1 | Provisional | Qualified 24 V driver or custom MOSFET power stage | Better long-term reliability path |
| Logic DC-DC | 1 | Locked | TOBSUN EA15-5V, 24 V to 5 V, 3 A, 15 W DC-DC converter | Mandatory powered-prototype 24 V to 5 V logic supply; current support preview places it below the BTS7960 on the lower support-spine landing |
| Fan DC-DC | 1 | Provisional | Pololu D24V10F12 | Fallback only if the stock 12 V cooler fan is retained; not needed in the current exact prototype order set |
| TEC branch fuse | 1 | Preferred | Bussmann ATM-10 | Put close to the PSU output branch point |
| Logic branch fuse | 1 | Preferred | Bussmann ATM-2 | Protect the logic buck and controller auxiliaries |
| TEC wiring | 1 lot | Preferred | BNTECHGO 16 AWG silicone wire, red and black | Keep runs short |
| Logic wiring | 1 lot | Preferred | Alpha Wire 3050, 24 AWG stranded hookup wire | Sensor, alarm, and low-current control wiring |

## Controller and sensing

| Item | Qty | Status | Recommended part / spec | Notes |
| --- | --: | --- | --- | --- |
| Main controller | 1 | Locked | Seeed Studio XIAO nRF52840 Plus, SKU 102010672 | BLE-capable MCU module with 9 extra SMD GPIO |
| Local HMI | 1 | Locked | Seeed Studio Round Display for XIAO, SKU 104030087 | 1.28 inch round touch display with RTC and TF slot |
| RTC backup cell | 1 | Provisional | CR927 coin cell | Only needed if RTC retention is desired without network sync |
| Controller interface board | 1 | Preferred | Custom interposer or interface PCB for XIAO Plus, Round Display, multi-point sensing, alarms, and driver interface | Recommended first PCBWay assembly target |
| Water temperature sensor | 1 | Locked | Adafruit Waterproof DS18B20, PID 381 | Main aquarium control input if the stock probe is not reused |
| Cold block temperature sensor | 1 | Locked | Analog Devices DS18B20+ | Use TO-92 package on a custom short lead for cold-side monitoring |
| Hot-side temperature sensor | 1 | Locked | Analog Devices DS18B20+ | Use TO-92 package on a custom short lead near the cooler base or heat-pipe root |
| Air intake temperature sensor | 1 | Locked | Analog Devices DS18B20+ | Use TO-92 package on a light lead support upstream of the fan |
| Air outlet temperature sensor | 1 | Locked | Analog Devices DS18B20+ | Use TO-92 package on a light lead support in the cooler exhaust stream |
| Ambient humidity sensor | 1 | Preferred | Adafruit SHT31-D breakout, PID 2857 | Current exact condensation-monitor choice |
| Leak sensor | 1 | Locked | DFRobot Gravity Water Sensor, SEN0205 | Included in the current dry-fit and dry-wire prototype; use as the thresholded leak-input path |
| Status indicator | 1 | Preferred | Mallory Sonalert PS-580Q | Local alarm |
| Driver interface buffer | 1 | Preferred | Texas Instruments SN74AHCT125PW | Treat as standard with the generic BTS7960 module |

## PCB and connectivity

| Item | Qty | Status | Recommended part / spec | Notes |
| --- | ---: | --- | --- | --- |
| Control PCB | 1 | Preferred | 4-layer FR-4, 1.6 mm, ENIG | XIAO Plus interface board with Round Display mating geometry |
| 24 V auxiliary power connector | 1 | Preferred | JST B2P-VH(LF)(SN) header, VHR-2N housing, SVH-21T-P1.1 contacts | Board-side J1 power entry family |
| Sensor connectors | several | Preferred | JST-PH family: B3B-PH-K-S(LF)(SN), B4B-PH-K-S(LF)(SN), PHR housings, SPH-002T-P0.5S contacts | Use 3-pin board-side connectors for temperature and leak, plus one 4-pin connector for humidity or auxiliary I2C |
| Temperature sensor harness | 1 | Preferred | Belden 9533, 24 AWG 3-conductor trunk with five labeled DS18B20 drops | Powered mode only; branch off-board near the support frame or thermal assembly |
| External driver interface connector | 1 | Preferred | JST B5B-XH-A(LF)(SN) header, XHP-5 housing, SXH-001T-P0.6 contacts | Board-side J2 control connector; the XIAO board should not carry TEC current |
| SWD pads | 1 set | Preferred | Tag-Connect TC2030-IDC-NL compatible footprint | For recovery and debugging |
| USB access | 1 | Preferred | StarTech USB31CSAFM1M panel-mount USB-C extension | Only needed if the XIAO USB-C cannot remain directly accessible |
| Round Display mating connector geometry | 1 set | Preferred | Exact XIAO-standard 2 x 7 footprint mapping on the custom interface board | Needed so the off-the-shelf Round Display can mate cleanly |

## Notes that matter

1. The current PSU is intentionally oversized relative to the TEC nameplate. That is deliberate margin, not a mistake.
2. The exact first powered-prototype driver is now locked to the approved IBT-2 Double BTS7960 43 A module, but a better-qualified upgrade path remains open if long-term reliability becomes the priority.
3. The XIAO Plus and Round Display should sit on a custom interface or interposer PCB, not float on wires.
4. High current for the TEC should stay off the first XIAO interface board.
5. The final hose-plug OD is not frozen until the three plastic hose-plug options are tested against the real Fluval hose.
6. The Round Display consumes most standard XIAO pins, so the additional Plus pads are now part of the control architecture, not just optional margin.
7. The current exact powered-prototype fan path uses a 24 V Noctua replacement fan on the Thermalright heatsink, so the prototype power tree stays on 24 V and 5 V rails only.
8. The current preview and wiring package assume the main 16.0 mm hose-plug option on both ports for the dry prototype.

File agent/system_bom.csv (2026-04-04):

Line | Category | Subsystem | Qty | Item | Manufacturer | MPN_or_Identifier | Specification | Status | Notes
1 | Thermal | Cold side | 1 | TEC module | Generic | TEC126306 / TEC1-26306 | 50x50mm 24V 6A nominal | Locked | Electrical input ceiling about 144W
2 | Thermal | Hot side | 1 | CPU air cooler | Thermalright | Assassin X 120 Refined SE | Intel LGA1700 or LGA1851 tower heatsink | Locked | Current exact heatsink choice for the powered prototype
2.1 | Thermal | Hot side | 1 | Prototype replacement fan | Noctua | NF-F12 industrialPPC-24V-2000 IP67 PWM | 120mm 24V PWM fan | Preferred | Use this fan on the chosen heatsink and set the bundled 12V fan aside in the current exact prototype build
3 | Thermal | Interface | 1 | Copper spreader | Custom | C110 copper plate | 60x60x5mm | Locked | Between TEC and CPU cooler
4 | Thermal | Interface | 1 | Thermal paste | Noctua | NT-H2 10g | Non-conductive thermal paste | Preferred | Use on TEC-metal interfaces
5 | Mechanical | Prototype | 1 | PLA cold block mockup | Custom | SCAD-driven prototype | Fit and geometry validation only | Locked | Use PLA first for lowest cost; do not use for thermal conclusions
5.1 | Mechanical | Prototype | 1 | Plastic support kit | Custom | Interlocking support kit | About 248x190mm assembled cradle/deck with display mast split PSU uprights and spine-keyed driver shelf | Preferred | Non-wet structural prototype for the powered mockup with fixed Mean Well side-mount holes; can be quoted separately
6 | Mechanical | Final wet part | 1 | CNC cold block lid | Custom | Inline cold block lid | 316L stainless steel | Locked | Thermal landing channel pack and upper wet path
7 | Mechanical | Final wet part | 1 | CNC cold block base | Custom | Inline cold block base | CNC POM | Locked | Lower wet path and O-ring groove; hybrid wet-part baseline
7.1 | Fluid | Hose interface | 2 | Final hose plugs | Custom | Replaceable hose plug | CNC POM | Locked | Separate trapped hose plugs; final OD follows prototype hose-plug fit result
8 | Mechanical | Sealing | 1 | O-ring or seal cord | TBD | EPDM 70A round cord | 2.0mm cross section | Provisional | Final cut length should follow the released groove dimension
9 | Mechanical | Assembly | 6 | Block screws | Generic | M3 x 30mm A2-70 socket-head cap screws | Prototype through-bolts | Preferred | Use with washers and nyloc nuts; do not rely on tapped POM for clamp load
9.1 | Mechanical | Assembly | 6 | Compression sleeves | Custom or generic | 316 stainless spacer | 3.2mm ID x 4.0mm OD x 24mm long | Preferred | Use with the POM base to control clamp load and reduce creep
10 | Mechanical | Insulation | 1 lot | Closed-cell foam | Armacell | AP ArmaFlex self-adhesive sheet | 6mm thick | Preferred | Insulate block and nearby tubing
11 | Fluid | Hose retention | 4 | Oetiker clamp set | Oetiker | 167-series stepless ear clamp | 304 stainless size after hose test | Preferred | Freeze exact clamp size only after the hose-plug OD is validated on the real hose
12 | Power | Main PSU | 1 | DC power supply | Mean Well | LRS-350-24 | 24V 14.6A 350.4W | Locked | Approved baseline supply
13 | Power | TEC driver prototype | 1 | H-bridge module | Generic | IBT-2 Double BTS7960 43A H-bridge module | 24V compatible external prototype TEC driver | Locked | Approved first powered-prototype driver; keep the board in the 50x50mm class that matches the current support reference
14 | Power | TEC driver upgrade | 1 | Qualified driver | TBD | 24V driver or custom MOSFET stage | Quality-focused path | Provisional | Preferred later reliability path
15 | Power | Logic supply | 1 | DC-DC buck | TOBSUN | EA15-5V | 24V to 5V 3A 15W DC-DC converter | Locked | Required for the powered prototype and intended for the lower support-spine mount below the BTS7960
16 | Power | Fan supply | 1 | DC-DC buck | Pololu | D24V10F12 | 24V to 12V buck fallback | Provisional | Only needed if the stock 12V cooler fan is retained instead of the current 24V Noctua replacement
17 | Power | Protection | 1 | TEC branch fuse | Bussmann | ATM-10 | 10A blade fuse | Preferred | Install near PSU output
18 | Power | Protection | 1 | Logic branch fuse | Bussmann | ATM-2 | 2A blade fuse | Preferred | Protect controller and auxiliaries
19 | Wiring | High current | 1 lot | TEC wiring | BNTECHGO | 16AWG silicone wire red black | Flexible high-current wire | Preferred | Keep short
20 | Wiring | Low current | 1 lot | Logic wiring | Alpha Wire | 3050 24AWG | Stranded hookup wire | Preferred | For sensors and logic
21 | Control | Main MCU | 1 | Wireless controller | Seeed Studio | 102010672 | Seeed Studio XIAO nRF52840 Plus | Locked | BLE-capable MCU module with 9 extra SMD GPIO
22 | Control | Local HMI | 1 | Touch display | Seeed Studio | 104030087 | Round Display for XIAO 1.28 inch touch RTC TF | Locked | Primary local UI and input device
23 | Control | RTC backup | 1 | RTC battery | TBD | CR927 coin cell | Optional RTC retention battery | Provisional | Only needed if RTC retention is desired
24 | Control | Interface board | 1 | XIAO Plus interface PCB | Custom | Controller interposer | Custom PCB for XIAO Plus Round Display multi-point sensing and driver interface | Preferred | Primary PCBWay PCBA target
25 | Sensing | Water temperature | 1 | Water temp probe | Adafruit | PID 381 | Waterproof DS18B20 probe | Locked | Main aquarium control sensor if the stock probe is not reused
26 | Sensing | Cold block temperature | 1 | Cold-side sensor | Analog Devices | DS18B20+ | TO-92 digital temperature sensor | Locked | Use on a short custom lead for cold-side monitoring
27 | Sensing | Hot side temperature | 1 | Heatsink sensor | Analog Devices | DS18B20+ | TO-92 digital temperature sensor | Locked | Use on a short custom lead near the cooler base or heat-pipe root
27.1 | Sensing | Air intake | 1 | Air intake temperature sensor | Analog Devices | DS18B20+ | TO-92 digital temperature sensor | Locked | Use on a light lead support ahead of the fan intake
27.2 | Sensing | Air outlet | 1 | Air outlet temperature sensor | Analog Devices | DS18B20+ | TO-92 digital temperature sensor | Locked | Use on a light lead support in the cooler exhaust stream
28 | Sensing | Humidity | 1 | Ambient humidity sensor | Adafruit | PID 2857 | SHT31-D breakout | Preferred | Can share D4 D5 bus with RTC and touch; keep out of the direct hot-air exhaust plume
29 | Sensing | Leak protection | 1 | Leak sensor | DFRobot | SEN0205 | Gravity Water Sensor | Locked | Included in the current dry-fit and dry-wire prototype as the thresholded leak-input path
30 | UI | Alarm | 1 | Status buzzer | Mallory Sonalert | PS-580Q | 5V buzzer | Preferred | Useful for failsafe events
31 | PCB | Assembly | 1 | Control PCB | Custom | 4-layer FR-4 ENIG | 1.6mm board | Preferred | XIAO Plus interface board with Round Display mating geometry
31.1 | PCB | Connectivity | 1 | 24V auxiliary power connector | JST | B2P-VH(LF)(SN) + VHR-2N + SVH-21T-P1.1 | Board-side J1 power-entry family | Preferred | Current exact 24V auxiliary connector family
32 | PCB | Connectivity | several | Sensor connectors | JST | JST-PH family | Use B3B and B4B headers with matching PHR housings and SPH contacts | Preferred | Use 3-pin connectors for temperature and leak plus one 4-pin connector for humidity or auxiliary I2C
32.1 | PCB | Connectivity | 1 | Temperature sensor harness | Belden | 9533 | 3-wire 1-Wire DS18B20 harness trunk with five labeled drops | Preferred | Powered mode only; branch off-board near the support frame or thermal assembly
33 | PCB | Logic interface | 1 | Driver buffer | Texas Instruments | SN74AHCT125PW | 3.3V in to 5V-compatible logic buffer | Preferred | Treat as standard with the BTS7960 module
33.1 | PCB | Connectivity | 1 | External driver interface connector | JST | B5B-XH-A(LF)(SN) + XHP-5 + SXH-001T-P0.6 | Board-side J2 control connector family | Preferred | XIAO board should not carry TEC current
33.2 | PCB | Debug | 1 | SWD debug cable | Tag-Connect | TC2030-IDC-NL | SWD cable and matching footprint | Preferred | Current exact recovery and debugging choice
33.3 | PCB | Connectivity | 1 | USB access extension | StarTech | USB31CSAFM1M | Panel-mount USB-C extension | Preferred | Only needed if direct XIAO USB-C access is blocked

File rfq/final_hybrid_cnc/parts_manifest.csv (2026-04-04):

part_id | quote_group | file_name | quantity | material | description | source
CNC-A | required | cold_block_lid.step | 1 | 316L stainless steel | Cold block lid with thermal landing and six straight channels | rfq/final_hybrid_cnc/exports/export_lid.scad
CNC-B | required | cold_block_base.step | 1 | CNC POM | Cold block base with seal groove and lower transition floors | rfq/final_hybrid_cnc/exports/export_base.scad
CNC-C | option_16_0 | hose_plug_main_16_0mm.step | 2 | CNC POM | Hose-plug pair at 16.0 mm OD with shared trapped root | rfq/final_hybrid_cnc/exports/export_plug_main.scad
CNC-D | option_15_4 | hose_plug_mid_15_4mm.step | 2 | CNC POM | Hose-plug pair at 15.4 mm OD with shared trapped root | rfq/final_hybrid_cnc/exports/export_plug_mid.scad
CNC-E | option_14_8 | hose_plug_small_14_8mm.step | 2 | CNC POM | Hose-plug pair at 14.8 mm OD with shared trapped root | rfq/final_hybrid_cnc/exports/export_plug_small.scad

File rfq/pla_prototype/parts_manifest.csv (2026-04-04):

part_id | quote_group | file_name | quantity | description | source
FIT-A | core | prototype_lid_base_bundle.stl | 1 | Block bundle STL with 1 cold block lid and 1 cold block base | rfq/pla_prototype/exports/export_prototype_lid_base_bundle.scad
FIT-B | core | prototype_hose_bundle.stl | 1 | Hose bundle STL with 2 copies each of the 16.0 mm 15.4 mm and 14.8 mm hose plugs | rfq/pla_prototype/exports/export_prototype_hose_bundle.scad
FIT-C | core | prototype_support_frame.stl | 1 | Interlocking prototype support kit with display mast split PSU uprights and spine-keyed driver shelf | rfq/pla_prototype/exports/export_prototype_support.scad

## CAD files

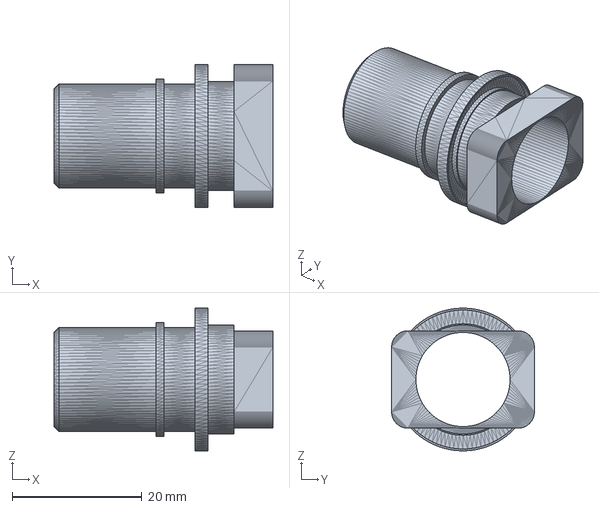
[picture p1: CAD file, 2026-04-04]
rfq/final_hybrid_cnc/step/hose_plug_main_16_0mm.step
33.8 x 22.0 x 22.0 mm

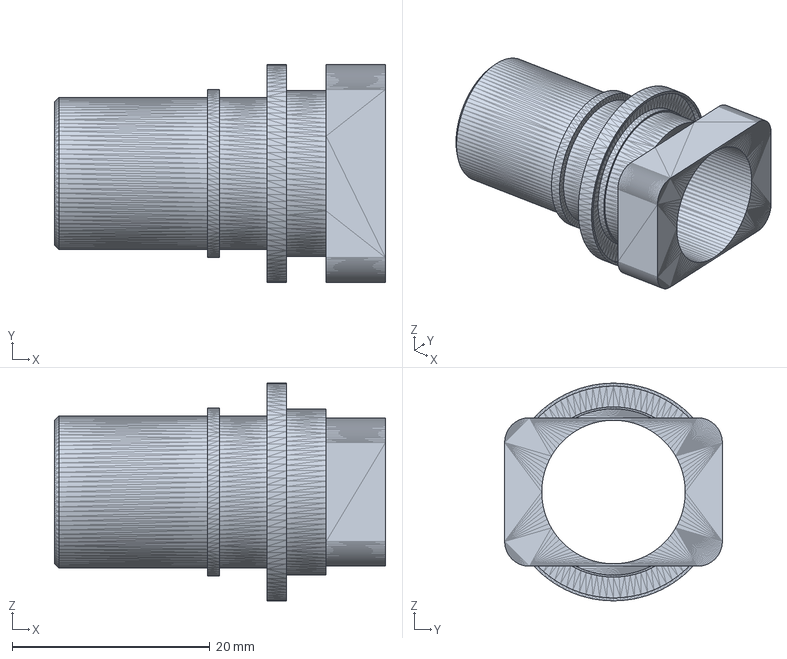
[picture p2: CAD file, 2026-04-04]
rfq/final_hybrid_cnc/step/hose_plug_mid_15_4mm.step
33.5 x 22.0 x 22.0 mm

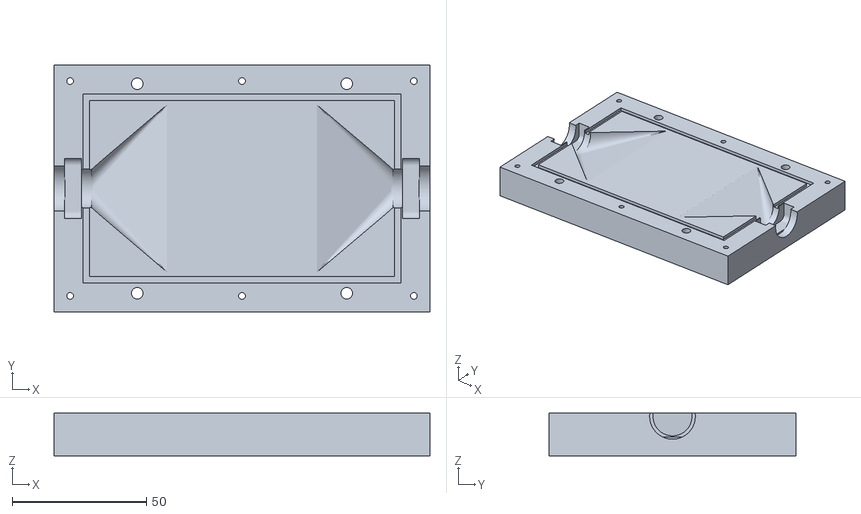
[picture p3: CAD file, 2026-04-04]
rfq/final_hybrid_cnc/stl/cold_block_base.stl
140.0 x 92.0 x 16.0

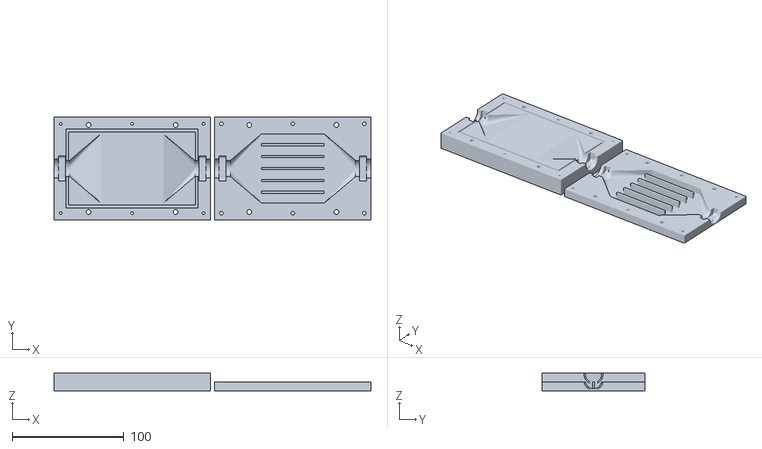
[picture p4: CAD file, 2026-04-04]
rfq/pla_prototype/stl/prototype_lid_base_bundle.stl
284.0 x 92.0 x 16.0

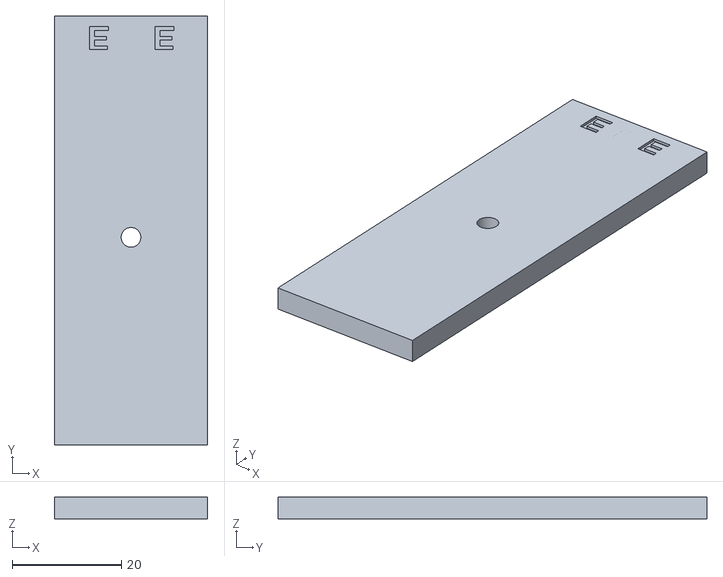
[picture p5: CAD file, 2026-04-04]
rfq/pla_prototype/stl/support_service/support_psu_upright.stl
28.0 x 78.5 x 4.00

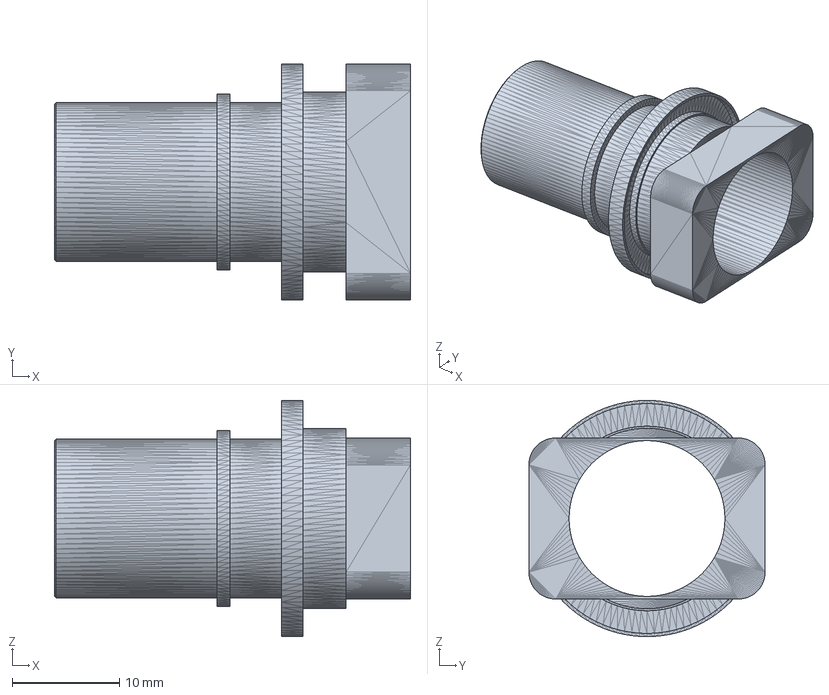
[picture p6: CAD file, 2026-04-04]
rfq/final_hybrid_cnc/step/hose_plug_small_14_8mm.step
33.1 x 22.0 x 22.0 mm

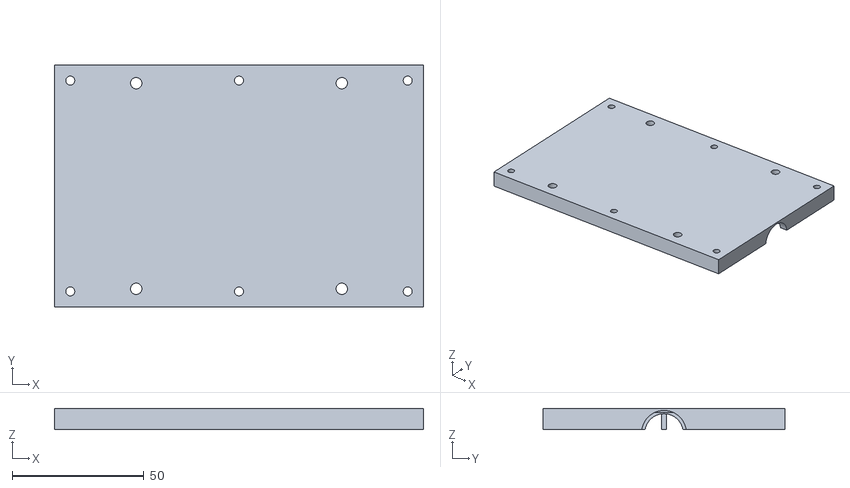
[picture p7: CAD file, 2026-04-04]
rfq/final_hybrid_cnc/stl/cold_block_lid.stl
140.0 x 92.0 x 8.00

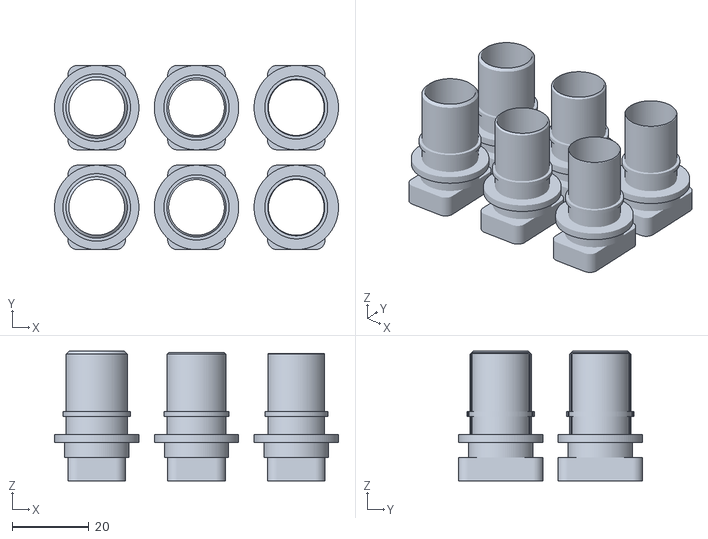
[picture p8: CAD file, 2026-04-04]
rfq/pla_prototype/stl/prototype_hose_bundle.stl
74.0 x 48.0 x 33.8

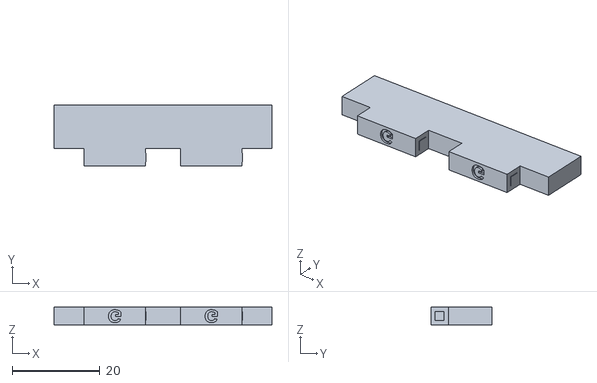
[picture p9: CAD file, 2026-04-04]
rfq/pla_prototype/stl/support_service/support_driver_shelf.stl
49.7 x 14.0 x 4.00

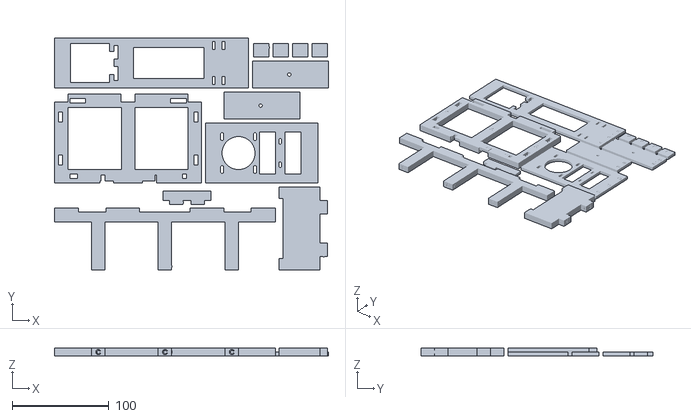
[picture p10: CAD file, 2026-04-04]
rfq/pla_prototype/stl/prototype_support_frame.stl
282.9 x 240.0 x 8.00

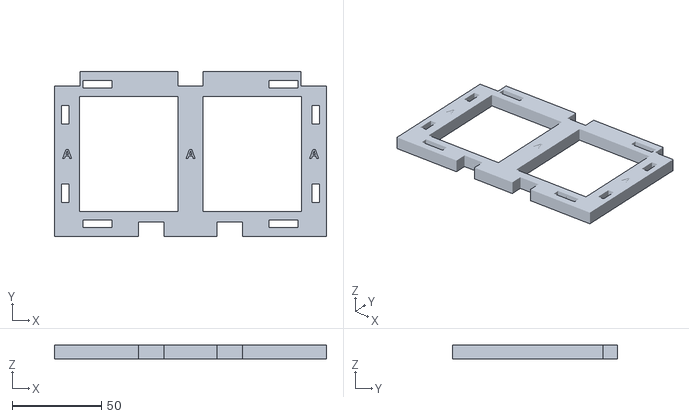
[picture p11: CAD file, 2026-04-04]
rfq/pla_prototype/stl/support_service/support_cradle_panel.stl
152.0 x 92.0 x 8.00

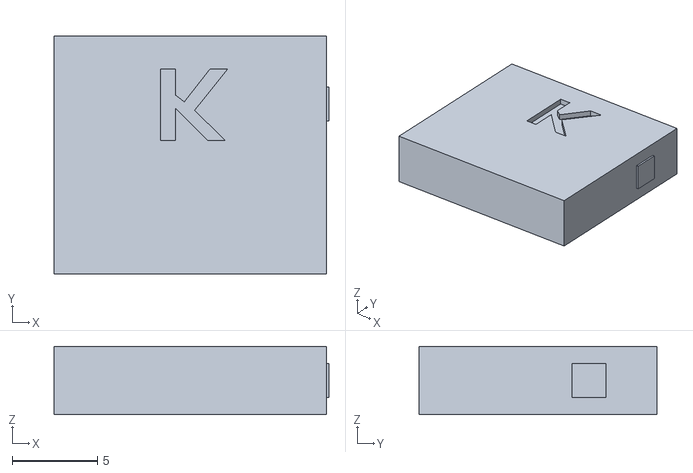
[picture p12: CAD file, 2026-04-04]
rfq/pla_prototype/stl/support_service/support_keeper.stl
16.1 x 14.0 x 4.00

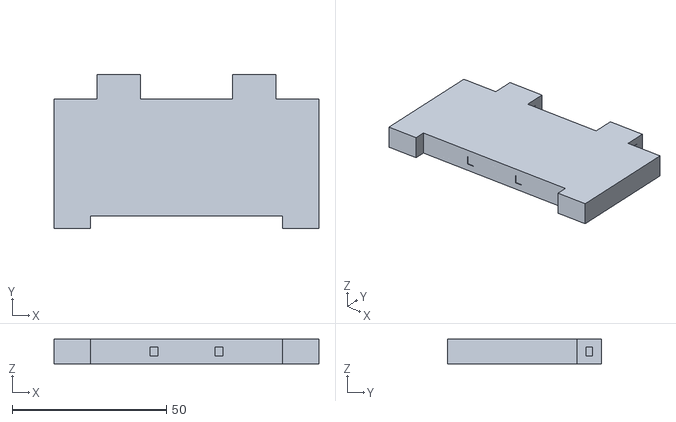
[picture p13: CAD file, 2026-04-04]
rfq/pla_prototype/stl/support_service/support_display_base.stl
86.0 x 50.0 x 8.00

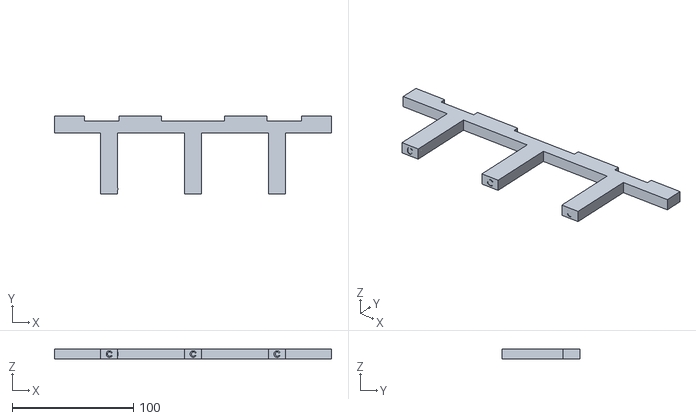
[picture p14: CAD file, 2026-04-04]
rfq/pla_prototype/stl/support_service/support_rear_deck.stl
228.0 x 64.0 x 8.00

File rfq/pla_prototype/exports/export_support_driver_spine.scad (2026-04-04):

use <../../../tec_cold_block_mockup.scad>

support_driver_spine_export();

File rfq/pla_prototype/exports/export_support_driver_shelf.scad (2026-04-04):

use <../../../tec_cold_block_mockup.scad>

support_driver_shelf_export();

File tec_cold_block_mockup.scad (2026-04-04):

$fn = 96;

part = "preview";
// preview | lid | base | plug_main | plug_mid | plug_small | coupon_main | coupon_mid | coupon_small | print_layout | prototype_lid_base_bundle | prototype_hose_bundle | prototype_hose_lid_base_bundle | prototype_support | prototype_support_assembly | prototype_preview

body_length = 140;
body_width = 92;
body_height = 24;

tec_size = 50;
tec_thickness = 4;
copper_size = 60;
copper_thickness = 5;

cooler_ref_length = 142;
cooler_ref_width = 120;
cooler_ref_height = 157;

lid_thickness = 8;
base_thickness = 16;
roof_thickness = 2;
boolean_overlap = 0.02;

spigot_length = 24;
main_spigot_od = 16.0;
mid_spigot_od = 15.4;
small_spigot_od = 14.8;
spigot_bead_height = 0.8;
spigot_bead_width = 1.2;
bead_offset_from_tip = 16.0;
entry_chamfer = 1.0;

plug_root_flange_od = 22.0;
plug_root_flange_thickness = 2.0;
plug_neck_od = 16.8;
plug_neck_length = 4.0;
plug_capture_head_y = 22.0;
plug_capture_head_z = 15.0;
plug_capture_head_length = 6.0;
plug_capture_head_radius = 2.5;
plug_socket_clearance = 0.15;
plug_throat_d = 17.0;
plug_gasket_id = 17.2;
plug_gasket_od = 21.4;
plug_gasket_recess_depth = 0.85;
plug_socket_end = plug_neck_length + plug_capture_head_length;
plug_layout_pitch = 58;

hose_id = 14.5;
bore_radius = hose_id / 2;
spigot_axis_y = body_width / 2;
spigot_axis_z = base_thickness - 1.25;

cavity_length = 112;
cavity_width = 62;
cavity_depth = 6;
transition_length = 28;
channel_run = 56;
channel_count = 6;
fin_width = 2;
side_wall = 0;
channel_width = (cavity_width - ((channel_count - 1) * fin_width) - (2 * side_wall)) / channel_count;

port_bore_x_overlap = 0.25;
lga1700_mount_pitch = 78;
hot_side_mount_clearance_d = 4.3;

support_length = 248;
support_width = 190;
support_beam_height = 8;
support_rail_width = 14;
support_crossmember_width = 14;
support_cradle_overhang = 6;
support_keeper_thickness = 4;
support_keeper_height = 14;
support_display_margin = 42;
support_display_panel_width = 62;
support_display_panel_height = 108;
support_display_panel_thickness = 4;
support_display_board_size = 43;
support_display_window_d = 34;
support_display_window_center_z = 82;
support_display_slot_pitch = 34;
support_display_slot_length = 8;
support_display_slot_width = 3.4;
support_controller_board_size = [21, 17.8];
support_controller_slot_pitch = 24;
support_controller_slot_length = 6;
support_controller_slot_width = 2.4;
support_display_relief_width = support_display_board_size;
support_display_relief_height = support_display_board_size;
support_display_relief_center_z = support_display_window_center_z - support_display_board_size;
support_controller_center_z = support_display_relief_center_z;
support_controller_bridge_height = 10;
support_psu_size = [215, 115, 30];
support_psu_mount_hole_d = 3.6;
support_psu_mount_pitch_x = 150;
support_psu_mount_offset_x = (support_psu_size[0] - support_psu_mount_pitch_x) / 2;
support_psu_mount_offset_z = 26.5;
support_rear_panel_margin_x = 10;
support_rear_panel_thickness = 4;
support_rear_panel_height = 168;
support_rear_gusset_depth = 18;
support_psu_vertical_clear_z = 6;
support_driver_total_depth = 43;
support_driver_outboard_depth = 24;
support_driver_inboard_depth = support_driver_total_depth - support_driver_outboard_depth;
support_driver_ref_size = [49.657, support_driver_total_depth, 49.403];
support_driver_shelf_width = support_driver_ref_size[0];
support_driver_shelf_depth = 10;
support_driver_shelf_thickness = 4;
support_driver_clear_above_psu = 6;
support_driver_cutout_margin = 4.5;
support_driver_cable_notch_width = 24;
support_driver_cable_notch_height = 12;
support_logic_buck_ref_size = [48, 19, 52];
support_logic_buck_mount_clear_z = 12;
support_logic_buck_slot_length = 8;
support_logic_buck_slot_height = 2.8;
support_logic_buck_slot_margin_x = 4;
support_logic_buck_strap_inset_z = 4.5;
support_hose_tab_thickness = 4;
support_hose_tab_width = 10;
support_hose_tab_height = 24;
support_hose_tab_slot_length = 10;
support_hose_tab_slot_width = 4;
support_hose_tab_body_gap = 6;
support_hose_tab_slot_center_z = support_beam_height + 6;
support_joint_clearance = 0.25;
support_plan_tab_length = 8;
support_plan_tab_width = 14;
support_driver_spine_width = 52;
support_shelf_tab_width = 14;
support_shelf_tab_offset = 8;
support_label_font = "Liberation Sans:style=Bold";
support_piece_label_depth = 0.6;
support_piece_label_size = 7;
support_small_label_size = 5;
support_slot_label_size = 4.5;
support_hidden_label_depth = 0.4;
support_hidden_large_label_size = 5.4;
support_hidden_medium_label_size = 4.4;
support_hidden_compact_label_size = 3.0;
support_plan_snap_depth = 0.12;
support_plan_snap_pocket_depth = 0.20;
support_plan_snap_length = 2.0;
support_plan_snap_height = 3.0;
support_vertical_snap_depth = 0.20;
support_vertical_snap_pocket_depth = 0.25;
support_vertical_snap_width = 2.5;
support_vertical_snap_height = 3.0;
support_small_snap_depth = 0.15;
support_small_snap_pocket_depth = 0.20;
support_small_snap_width = 2.0;
support_small_snap_height = 2.0;

cavity_x0 = (body_length - cavity_length) / 2;
cavity_y0 = (body_width - cavity_width) / 2;
channel_x0 = cavity_x0 + transition_length;
channel_x1 = channel_x0 + channel_run;
cavity_z0 = body_height - roof_thickness - cavity_depth;

landing_size = 64;
landing_margin = (body_length - landing_size) / 2;
landing_y = (body_width - landing_size) / 2;

support_body_x0 = (support_length - body_length) / 2;
support_body_y0 = support_display_margin;
support_rear_span_y0 = support_body_y0 + body_width;
support_psu_vertical_size = [support_psu_size[0], support_psu_size[2], support_psu_size[1]];
support_rear_panel_x0 = support_rear_panel_margin_x;
support_rear_panel_length = support_length - (2 * support_rear_panel_margin_x);
support_rear_panel_y0 = support_width - support_rear_panel_thickness;
support_psu_ref_x0 = (support_length - support_psu_vertical_size[0]) / 2;
support_psu_ref_y0 = support_rear_panel_y0 - support_psu_vertical_size[1];
support_psu_ref_z0 = support_beam_height + support_psu_vertical_clear_z;
support_display_panel_x0 = support_body_x0 + ((body_length - support_display_panel_width) / 2);
support_display_center_x = support_body_x0 + (body_length / 2);
support_driver_shelf_x0 = (support_length - support_driver_shelf_width) / 2;
support_driver_shelf_y0 = support_rear_panel_y0 + support_rear_panel_thickness;
support_driver_shelf_z0 = support_psu_ref_z0 + support_psu_vertical_size[2] + support_driver_clear_above_psu;
support_driver_ref_x0 = support_driver_shelf_x0;
support_driver_ref_y0 = support_rear_panel_y0 + support_rear_panel_thickness - support_driver_inboard_depth;
support_driver_ref_z0 = support_driver_shelf_z0 + support_driver_shelf_thickness;
support_cradle_x0 = support_body_x0 - support_cradle_overhang;
support_cradle_length = body_length + (2 * support_cradle_overhang);
support_cradle_depth = body_width;
support_display_base_x0 = support_display_panel_x0 - 12;
support_display_base_width = support_display_panel_width + 24;
support_display_base_depth = support_body_y0;
support_rear_deck_x0 = support_rear_panel_x0;
support_rear_deck_length = support_rear_panel_length;
support_rear_deck_depth = (support_width - support_rear_span_y0) + support_plan_tab_length;
support_driver_spine_x0 = (support_length - support_driver_spine_width) / 2;
support_driver_spine_height = support_driver_ref_z0 + support_driver_ref_size[2] + 12;
support_logic_buck_ref_x0 = (support_length - support_logic_buck_ref_size[0]) / 2;
support_logic_buck_ref_y0 = support_rear_panel_y0 + support_rear_panel_thickness;
support_logic_buck_ref_z0 = support_beam_height + support_logic_buck_mount_clear_z;
support_psu_upright_width = 28;
support_psu_upright_height = support_psu_ref_z0 + support_psu_mount_offset_z + 38;
support_psu_upright_x = [
    support_psu_ref_x0 + support_psu_mount_offset_x - (support_psu_upright_width / 2),
    support_psu_ref_x0 + support_psu_vertical_size[0] - support_psu_mount_offset_x - (support_psu_upright_width / 2)
];
support_spine_slot_x = [
    support_shelf_tab_offset,
    support_driver_spine_width - support_shelf_tab_width - support_shelf_tab_offset
];
support_shelf_tab_x = [
    support_driver_spine_x0 + support_spine_slot_x[0] - support_driver_shelf_x0,
    support_driver_spine_x0 + support_spine_slot_x[1] - support_driver_shelf_x0
];
support_keeper_slot_y = [
    support_body_y0 + ((support_rail_width - support_keeper_thickness) / 2),
    support_body_y0 + body_width - support_rail_width + ((support_rail_width - support_keeper_thickness) / 2)
];
support_hose_tab_pair_offset = (plug_root_flange_od / 2) + support_hose_tab_body_gap + support_hose_tab_width;
support_hose_tab_mount_x = [
    support_cradle_x0 + 4,
    support_cradle_x0 + support_cradle_length - support_hose_tab_thickness - 4
];
support_hose_tab_mount_y = [
    support_body_y0 + (body_width / 2) - support_hose_tab_pair_offset,
    support_body_y0 + (body_width / 2) + support_hose_tab_pair_offset - support_hose_tab_width
];
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

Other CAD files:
rfq/pla_prototype/stl/support_service/support_driver_spine.stl
rfq/pla_prototype/stl/support_service/support_display_mast.stl
rfq/pla_prototype/stl/support_service/support_hose_tab.stl
rfq/final_hybrid_cnc/exports/export_base.scad
rfq/final_hybrid_cnc/exports/export_lid.scad
rfq/final_hybrid_cnc/exports/export_plug_main.scad
rfq/final_hybrid_cnc/exports/export_plug_mid.scad
rfq/final_hybrid_cnc/exports/export_plug_small.scad
rfq/final_hybrid_cnc/stl/hose_plug_main_16_0mm.stl
rfq/final_hybrid_cnc/stl/hose_plug_mid_15_4mm.stl
rfq/final_hybrid_cnc/stl/hose_plug_small_14_8mm.stl
rfq/pla_prototype/exports/export_base.scad
rfq/pla_prototype/exports/export_coupon_main.scad
rfq/pla_prototype/exports/export_coupon_mid.scad
rfq/pla_prototype/exports/export_coupon_small.scad
rfq/pla_prototype/exports/export_lid.scad
rfq/pla_prototype/exports/export_plug_main.scad
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

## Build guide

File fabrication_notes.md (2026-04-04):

# TEC Cold Block Prototype Notes

This folder contains the first-pass OpenSCAD source for the low-restriction 6-channel inline cold block, the interchangeable hose-plug size options, and the open prototype support frame.

## Files

- `tec_cold_block_mockup.scad`: Parametric model for the two-piece block, three hose-plug size options, the interlocking support kit, and preview views.
- `README.md`: Consolidated project overview with the current SVG gallery and key notes.
- `whole_block_preview.svg`: Assembled block reference sheet.
- `cold_block_lid_preview.svg`: Lid-half reference sheet for the thermal face, underside channels, and lid depth control.
- `cold_block_base_preview.svg`: Base-half reference sheet for the split-plane face, seal groove, and lower water-path role.
- `hose_fit_coupons_preview.svg`: Hose-plug sizing option reference sheet.
- `cold_block_combined_preview.svg`: One-sheet combined overview of the block, lid, base, and hose-plug option set.
- `powered_prototype_component_layout.svg`: Powered-prototype component placement sheet.
- `powered_prototype_electrical_block.svg`: Powered-prototype simplified electrical block sheet.

All preview SVGs are reference diagrams in mm. Treat them as not-to-scale communication sheets, not as the sole manufacturing drawing for release.

## Current geometry

- Body excluding hose plugs: 140 x 92 x 24 mm
- Lid thickness: 8 mm
- Base thickness: 16 mm
- Hose bore target: 14.5 mm minimum through path
- Main installed hose-plug OD: 16.0 mm
- Extra hose-plug options: 15.4 mm and 14.8 mm
- Hose-plug projection from block face: 24 mm
- Hot-side cooler mount: 4 x Intel LGA1700 / LGA1851 clearance holes on a 78 x 78 mm square
- Cavity envelope: 112 x 62 x 6 mm
- Channel set: 6 channels, each about 8.67 x 56 x 6 mm
- Fin thickness: 2 mm
- Side wall thickness inside cavity: 0 mm dedicated side walls, so the outer channels run to the cavity edge
- Inlet and outlet transition length: 28 mm each
- Prototype support frame: interlocking flat-part support kit, about 248 x 190 mm assembled footprint
- Support frame structure: 8 mm cradle panel plus rear deck, separate side display mast, split rear PSU uprights with fixed Mean Well LRS-350-24 side-mount holes on the 150 mm long-axis pitch, a narrow center driver spine, a rear-facing Double BTS7960 mount with the heatsink outboard plus a compact lower tie-slot landing for an external 24 V to 5 V logic buck, a large pass-through window above that buck zone, a widened lower cable notch behind the driver board, and low hose strain-relief tabs aligned with the block base and spigot bead position
- Support kit identification: major support parts now carry simple engraved A-G / K / T IDs, with matching mating marks on the main interlock panels for faster sorting and reassembly
- O-ring groove centerline rectangle: 116 x 68 mm
- O-ring groove width/depth: 2.4 x 1.5 mm

## Intent of this revision

- Keep the minimum internal flow area at or above the Fluval hose area.
- Use 6 wider channels that fill the full cavity width without extra side-wall ribs.
- Keep the ports smooth and full-bore, with the transition split across lid and base.
- Use the low-cost PLA round only to verify fit, clearance, hose engagement, and overall geometry.
- Keep the thermal stack structurally supported by the block cradle, not by the LGA1700 / LGA1851 clamp holes.
- Keep the controller and display on the open side mast so the XIAO antenna is not buried behind the PSU or cooler fins.
- Keep the final wet-part material decision separate from the plastic fit round.

## OpenSCAD usage

Change the `part` variable at the top of the file:

- `preview`: Assembled block, hose-plug options, and TEC/copper references
- `prototype_preview`: Block mounted on the interlocking support kit with cooler, PSU, driver, and side-HMI references
- `lid`: Lid half only
- `base`: Base half only
- `plug_main`: 16.0 mm OD hose plug
- `plug_mid`: 15.4 mm OD hose plug
- `plug_small`: 14.8 mm OD hose plug
- `coupon_main`, `coupon_mid`, `coupon_small`: legacy aliases for the same three hose-plug exports
- `print_layout`: Bed layout with base, lid, and the three hose-plug options
- `prototype_lid_base_bundle`: Upload bundle with 1 base and 1 lid in one STL
- `prototype_hose_bundle`: Upload bundle with 2 copies each of the 16.0 mm, 15.4 mm, and 14.8 mm hose plugs in one STL
- `prototype_support`: Flat interlocking support-part layout for printing

Support service reprints:

- `rfq/pla_prototype/exports/export_support_*.scad`: wrapper exports for individual cradle, deck, mast, upright, spine, shelf, keeper, and hose-tab parts
- VS Code task `Export OpenSCAD Prototype Support Service STL Set`: writes single-part replacement STLs to `rfq/pla_prototype/stl/support_service`

## What to validate on the plastic prototype print

- Hose grip on all three hose-plug diameters
- How far the Fluval hose can be pushed over the bead without damage
- Clearance around the canister, tubing bends, and insulation volume
- Screw access and whether the body size is still comfortable in the install space
- Whether the chosen LGA1700 / LGA1851 cooler bracket sits cleanly on the new hot-side mount holes
- Whether the 6-screw layout still clamps the lid evenly enough around the long sides
- Whether the 16.0 mm OD best-guess hose plug should stay, reduce to 15.4 mm, or reduce to 14.8 mm
- Whether the trapped plug pockets seat the plug roots cleanly when the lid and base are clamped
- Whether the support frame clears the real cooler fan clips, the vertical PSU terminal side, and the rear wiring exits
- Whether the low hose strain-relief tabs and shifted spigot bead position land in the right place for the real hose clamp and bend radius

## What not to validate on the plastic prototype print

- Final leak performance
- Final thermal performance
- Final surface finish of the diffusers or channel entries
- Long-term clamp load or thread durability

## Final hybrid revision notes

- Materials: 316L stainless steel lid, CNC POM base, and separate CNC POM hose plugs for the wet assembly
- Keep the 14.5 mm minimum bore all the way through the final part
- Hand polish the inlet and outlet diffusers after machining
- Deburr every channel entry and every bore intersection
- Do not introduce barbed features that neck the bore down below the hose ID
- Final hose-plug OD should follow the prototype hose-plug fit result
- Do not rely on a food-safe coating over a printed part as the final water barrier

## Suggested next iteration after fit test

- Lock the hose-plug OD from the prototype plug round
- Decide whether to keep the 24 mm spigot length or extend it by 3 to 5 mm
- Add any external flats, reliefs, or mounting features needed for the actual install
- Lock the real display hole pattern and confirm the fixed Mean Well side-mount pair with real hardware if the interlocking support kit is kept for the powered prototype
- Freeze the hybrid lid/base/plug set and then produce a machining drawing from the same geometry

## Related files

- `README.md`: Consolidated overview and SVG gallery.
- `whole_block_preview.svg`: Assembled block reference sheet.
- `cold_block_lid_preview.svg`: Lid-half reference sheet.
- `cold_block_base_preview.svg`: Base-half reference sheet.
- `hose_fit_coupons_preview.svg`: Hose-plug sizing option reference sheet.
- `cold_block_combined_preview.svg`: Combined overview sheet.
- `powered_prototype_component_layout.svg`: Powered-prototype component placement sheet.
- `powered_prototype_electrical_block.svg`: Powered-prototype simplified electrical block sheet.

All preview SVGs remain reference-only support sheets. The final hybrid release still needs formal CAD plus a manufacturing drawing generated from the frozen geometry.

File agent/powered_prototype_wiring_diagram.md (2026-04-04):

# Powered Prototype Wiring Diagram

This file is the wiring reference for the current dry-fit and dry-wire powered prototype.

Use `powered_prototype_electrical_block.svg` as the primary color-coded wiring sheet and `powered_prototype_component_layout.svg` as the companion 2D placement sheet.

## Build assumptions

- use the main 16.0 mm hose-plug option on both ports for the current component sheet and dry prototype
- use the printed prototype only for full assembly, cable routing, clamp access, and dry leak-sensor placement; do not run water through the printed wet-path parts
- include the leak sensor in the current harness and mount it under the block area for cabinet-floor drip detection
- use the TOBSUN EA15-5V buck below the BTS7960 on the support spine

## Harness legend

| Harness ID | Color in wiring diagram | Conductors | Target wire | Source | Destination | Target cut length |
| --- | --- | ---: | --- | --- | --- | ---: |
| H_PWR_TEC_PSU_DRIVER | Red | 2 | 16 AWG silicone pair | PSU 24 V output | IBT-2 power input | 280 mm |
| H_PWR_TEC_DRIVER_TEC | Orange | 2 | 16 AWG silicone pair | IBT-2 motor output | TEC module | 260 mm |
| H_PWR_AUX_24V | Blue | 2 | 24 AWG pair | PSU auxiliary branch after ATM-2 fuse | TOBSUN EA15-5V input | 220 mm |
| H_PWR_5V | Cyan | 2 | 24 AWG pair | TOBSUN EA15-5V output | XIAO VBUS and logic branch | 420 mm |
| H_CTRL_DRIVER | Purple | 5 | 24 AWG bundle | XIAO and SN74AHCT125PW | IBT-2 control header | 360 mm |
| H_FAN | Yellow | 4 | 24 AWG bundle | PSU auxiliary 24 V plus XIAO PWM and tach | Noctua NF-F12 24 V PWM fan | 320 mm |
| H_TEMP | Green | 3 trunk plus 5 drops | Belden 9533 trunk plus DS18B20 drops | XIAO 1-Wire bus | all five DS18B20 probes | see temperature schedule below |
| H_HUMID | Teal | 4 | 24 AWG bundle | XIAO I2C branch | Adafruit SHT31-D breakout  | 260 mm |
| H_LEAK | Amber | 3 | 24 AWG bundle | XIAO leak-input branch | DFRobot SEN0205 | 240 mm |
| H_ALARM | Magenta | 2 | 24 AWG pair | XIAO alarm output | Mallory Sonalert PS-580Q | 180 mm |

Temperature schedule for H_TEMP:

| Branch | Target cut length |
| --- | ---: |
| J3 trunk to S_TEMP splice | 280 mm |
| T_WATER | 1200 mm |
| T_COLD | 200 mm |
| T_HOT | 180 mm |
| T_AIR_IN | 220 mm |
| T_AIR_OUT | 100 mm |

## Wiring topology

```mermaid
flowchart LR
    PSU["Mean Well LRS-350-24\n24 V PSU"]
    FTEC["Bussmann ATM-10\nTEC fuse"]
    FAUX["Bussmann ATM-2\naux fuse"]
    BTS["IBT-2 Double BTS7960\nTEC driver"]
    BUCK["TOBSUN EA15-5V\n24 V to 5 V buck"]
    CTRL["Seeed XIAO nRF52840 Plus\nwith Round Display"]
    BUF["SN74AHCT125PW\ndriver buffer"]
    FAN["Noctua NF-F12\n24 V PWM fan"]
    SPLICE["S_TEMP\n1-Wire splice"]
    TW["T_WATER\nDS18B20"]
    TC["T_COLD\nDS18B20"]
    TH["T_HOT\nDS18B20"]
    TIN["T_AIR_IN\nDS18B20"]
    TOUT["T_AIR_OUT\nDS18B20"]
    HUM["Adafruit SHT31-D\nPID 2857"]
    LEAK["DFRobot SEN0205\nleak sensor"]
    ALARM["PS-580Q\nbuzzer"]
    TEC["TEC126306\nTEC module"]

    PSU -->|H_PWR_TEC_PSU_DRIVER| FTEC --> BTS
    BTS -->|H_PWR_TEC_DRIVER_TEC| TEC
    PSU -->|H_PWR_AUX_24V| FAUX
    FAUX -->|H_PWR_AUX_24V| BUCK
    FAUX -->|H_FAN 24 V and GND| FAN
    BUCK -->|H_PWR_5V| CTRL
    CTRL -->|H_CTRL_DRIVER| BUF --> BTS
    CTRL -->|H_FAN PWM and TACH| FAN
    CTRL -->|H_TEMP| SPLICE
    SPLICE -->|T_WATER| TW
    SPLICE -->|T_COLD| TC
    SPLICE -->|T_HOT| TH
    SPLICE -->|T_AIR_IN| TIN
    SPLICE -->|T_AIR_OUT| TOUT
    CTRL -->|H_HUMID| HUM
    CTRL -->|H_LEAK| LEAK
    CTRL -->|H_ALARM| ALARM
```

## Mounting intent for the dry prototype

| Part | Current mounting intent |
| --- | --- |
| TOBSUN EA15-5V | lower support spine, below the BTS7960, strap-mounted to the rear face |
| IBT-2 BTS7960 | rear face of the support spine with the heatsink outboard |
| XIAO and Round Display | display-side mast and lower opening band |
| S_TEMP splice | inside face of the rear panel, centered laterally and below the driver shelf |
| Adafruit SHT31-D | inside face of the rear panel on the display side, above block height and out of the exhaust plume |
| DFRobot SEN0205 | on the support floor under the block envelope for drip-detection routing and dry assembly checks |
| PS-580Q buzzer | front display-base area for audible bench alerts |

## Notes that matter

1. The dry-build wiring package intentionally includes the leak sensor now so routing, connector access, and floor clearance can be checked before any wet testing.
2. The current wiring document is for physical harness planning and coordination with the 2D powered-prototype reference sheets; the SVG is the visual wiring sheet, but neither file replaces the future controller schematic.
3. If hose-fit testing later changes the final hose-plug OD, update the manuals and RFQ notes, not the current dry prototype wiring layout.

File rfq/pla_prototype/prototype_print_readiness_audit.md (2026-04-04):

# Prototype Print Readiness Audit

Date: 2026-04-03

## Scope

This audit covers the PLA-first fit and geometry prototype package for the printed cold-block parts and the required interlocking support kit.

## Audit result

- ready to prepare and send the prototype print package
- no blocking documentation gaps found for the PLA print quote round
- final hybrid CNC release remains intentionally out of scope and still gated on hose-plug testing

## Passed checks

- RFQ package text exists and is aligned to the PLA-first fit-only scope.
- Quote message, parts manifest, and send checklist are present and consistent.
- The STL output folder contains the lid/base bundle STL, the hose bundle STL, and the support kit STL needed for the current PLA upload workflow.
- Export wrapper SCAD files exist for all prototype print outputs.
- The reusable export task is present and has already been run successfully.
- Prototype documentation now states mm units explicitly.
- Prototype documentation now requires approval before geometry changes.
- Supplemental SVGs are correctly treated as optional, reference-only, and not-to-scale.
- The SVG set itself already carries units, source-of-truth, and reference-only metadata in case PCBWay asks for extra visual context.

## Primary send set

- `rfq/pla_prototype/stl/prototype_lid_base_bundle.stl`
- `rfq/pla_prototype/stl/prototype_hose_bundle.stl`
- `rfq/pla_prototype/stl/prototype_support_frame.stl`
- `rfq/pla_prototype/parts_manifest.csv`
- `rfq/pla_prototype/pla_quote_message.txt`

## Controlled caution

- Do not let the print vendor simplify, smooth, resize, or otherwise alter geometry without approval.
- Do not treat the prototype package as a wet-service or final manufacturing release.
- Do not start the final hybrid RFQ until the printed hose-plug options validate the real hose fit.

## Immediate next action

- Upload the three prototype STL files together with `parts_manifest.csv` and `pla_quote_message.txt`.

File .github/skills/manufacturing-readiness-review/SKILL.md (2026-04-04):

---
name: manufacturing-readiness-review
description: "Validate whether the aquarium TEC project is ready to send for prototype or manufacture. Use for industrial-design review, best-practice checks, file alignment, export/package completeness, and release blocker identification."
user-invocable: true
---

# Manufacturing Readiness Review

## When To Use

- checking whether the PLA prototype package is ready to send for quote
- checking whether the hybrid CNC package is ready for quote or final release
- reviewing whether files, manifests, exports, and RFQ notes are aligned before supplier handoff
- asking for a best-practice pass that thinks like an industrial designer, not just a geometry exporter

## Procedure

1. Read `agent/agent.md`, `agent/pcbway_handoff.md`, and `agent/validation_and_open_items.md`.
2. Read [release-readiness-checklist.md](./references/release-readiness-checklist.md).
3. Read `.github/references/professional-drawing-and-cad-standards.md` and the RFQ package files in scope.
4. Compare source geometry, wrapper exports, generated STLs/STEPs/CSGs, manifests, quote messages, fabrication notes, reference SVGs, multi-part print orientations and packing efficiency, and open stage-gate items.
5. Fix small in-repo drift directly when it is safe to do so.
6. Keep any physical-test dependency or missing-release-document issue as an explicit blocker instead of pretending it is closed.
7. Use [verdict-template.md](./references/verdict-template.md) to report the outcome.

## Rules

- think like an industrial designer: prioritize assembly clarity, service access, hose and clamp usability, intentional placement of user-facing parts, and a package that is easy for a vendor to understand without guesswork
- for interlocking prototype kits, prefer hidden mirrored witness letters and light PLA detents over exposed face labels or glue-only plain joints
- require consistent part naming, quantities, materials, dimensions, and status statements across package docs and exported files
- treat scattered multi-part prototype print exports or support-heavy orientations as package drift when a tighter support-light layout is available
- treat preview SVGs as reference-only support sheets unless a formal drawing package exists separately
- do not call a final hybrid wet-part package release-ready until the real-hose plug test freezes the OD and a formal 2D manufacturing drawing or PDF exists
- keep PCBWay ambiguity-reduction guidance above convenience; if orientation, ownership, or assembly order could be misread, add explicit notes, drawings, or marked images
- prefer the smallest coherent set of file edits needed to restore package alignment

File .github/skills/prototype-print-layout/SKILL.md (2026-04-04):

---
name: prototype-print-layout
description: "Design and review multi-part 3D-print export layouts for the aquarium TEC prototype. Use for STL bundle packing, print orientation, support avoidance, bed-footprint reduction, and keeping bundled prototype parts tightly packed in one print-ready layout."
user-invocable: true
---

# Prototype Print Layout

## When To Use

- creating or revising any SCAD export mode that contains more than one printed part
- tightening PLA-first STL bundles for PCBWay or local FDM printing
- checking whether a print bundle is support-light, compact, and easy to identify after printing
- checking whether interlocking prototype parts carry hidden matching joint cues instead of exposed assembly labels
- deciding how to orient lids, bases, hose plugs, and support pieces so print cost stays low without hiding geometry problems

## Procedure

1. Read `agent/mechanical_design.md` and `agent/pcbway_handoff.md`.
2. Read `tec_cold_block_mockup.scad` and the relevant wrapper exports under `rfq/`.
3. Identify every part in the bundle and choose its print orientation before moving anything for packing.
4. Pack the parts into the smallest coherent XY footprint that still leaves enough clearance for reliable printing and cleanup.
5. Regenerate the STL and verify that every part sits on the same build plane with no accidental upside-down placement.
6. If the bundle contains interlocking joints, keep the witness letters on buried mating faces and use only light PLA-safe detents that help alignment without turning into brittle clips.
7. If the RFQ notes or package docs mention the bundle, update them so the written instructions match the exported layout.

## Rules

- do not leave multi-part print exports scattered around the bed when a tighter layout is possible
- do not choose a visually neat orientation if it creates avoidable supports, trapped internal support, or a larger footprint than necessary
- do not place open channels, grooves, plug pockets, or other cavity faces down unless there is no better stable orientation
- do not lay hose plugs horizontally when a vertical bore-up orientation is practical
- do not use arbitrary large gaps between parts; keep spacing small and justified
- do not place assembly letters on exposed finished-facing support surfaces when the same cue can live on the buried joint faces
- do not add large or aggressive snap hooks to PLA prototype joints when a shallow detent will locate the part just as well
- if two parts cannot both be packed tightly and printed cleanly in one bundle, split the export intentionally instead of shipping a support-heavy compromise

## Best Practices

### Orientation First

- Put the broadest flat, low-risk exterior face on the bed whenever that avoids supports.
- For split cold-block halves, prefer the smooth external face down and keep the split-face features up.
- Keep open cavities, channels, seal grooves, and plug-capture geometry facing up whenever possible so the slicer does not fill them with support.
- Keep long internal bores vertical when practical. For the aquarium hose plugs, the default should be hose axis vertical with the hose end up and the trapped-head side on the bed.
- If a part has one face that is flat but functionally delicate, decide whether a support-free orientation still wins for the prototype phase. For this project's PLA-first fit parts, support avoidance and footprint reduction usually outrank cosmetic surface quality.

### Packing Strategy

- Treat the bundle like one manufactured print job, not a loose collection of unrelated parts.
- Start with the largest two-dimensional footprints first, then fit the smaller parts into the remaining envelope.
- Prefer layouts that minimize the final bounding rectangle rather than layouts that merely look symmetric.
- Keep all parts on the same bed plane at `z = 0`; never leave floating geometry in an export bundle.
- Keep the origin simple and positive so regenerated STLs are predictable and easy to compare.
- Use one consistent gap for the bundle unless a specific part needs more. For this project's PLA bundles, `4 mm` is the default starting point and should only increase when geometry truly needs it.

### Project-Specific Defaults

- Cold-block base: print with the broad flat outer base face down. Do not flip the O-ring groove or split face onto the bed.
- Cold-block lid: print with the broad flat top face down. Do not place the channel face or split face on the bed.
- Hose plugs: stand them upright so the 14.5 mm bore stays vertical and the hose side points up.
- Repeated hose plugs: keep like parts in a simple row-and-column arrangement with identical orientation.
- Mixed bundles: keep the large body parts tightly packed first, then place the hose plugs in the smallest leftover band that does not increase the bounding box more than necessary.
- Interlocking support parts: keep mirrored witness letters on both sides of the mating joint and make sure those marks disappear once the joint is fully seated.
- PLA detents: prefer very small alignment bumps or pockets on the mating tongues, tabs, or stems instead of exposed hooks; they should help dry-fit alignment and glue-up without fighting clamps.

### Release Checks

- Confirm every part is resting on the intended bed face after any mirror or rotation step.
- Confirm no part requires hidden internal support in a bore or cavity that should have printed open.
- Confirm the packed export really reduced the footprint; do not assume the new layout is better just because the parts are closer together.
- When a print-layout convention changes materially, update the RFQ docs and the relevant agent guidance in the same pass.

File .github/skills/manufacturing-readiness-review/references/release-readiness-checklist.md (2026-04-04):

# Release Readiness Checklist

Use this checklist to judge whether the project is ready to send for prototype quote, manufacturing quote, or final release.

## 1. Review Scope

- Define the package under review: PLA fit prototype, hybrid CNC wet part, controller PCB/PCBA, or full repo coherence pass.
- State whether the target is quote-ready, prototype-ready, or final-release ready.

## 2. Source-Of-Truth Alignment

- Confirm the source-of-truth model or schematic package is identified clearly.
- Confirm wrapper export files exist for the parts being quoted.
- Confirm the generated outputs in the package match the parts named in the manifest and RFQ text.
- Confirm part names, quantities, materials, and dimensional claims agree across manifests, package notes, and quote messages.
- Confirm the package does not imply a newer release status than the actual validation state supports.

## 3. Industrial Design Coherence

- The part family reads as one intentional system rather than a pile of disconnected exports.
- Assembly order is understandable from the package without hidden tribal knowledge.
- Hose routing, clamp reach, screw access, display placement, PSU access, and service clearances are either validated or clearly marked as open.
- Multi-part prototype hardware includes enough identification, orientation cues, or notes to avoid assembly confusion.
- Human-facing visuals explain ownership, split lines, and reference-only status without relying on color alone.

## 4. Manufacturing Communication Quality

- Units are in mm.
- Materials are explicit.
- Finish and post-process expectations are stated where they matter.
- Critical-to-function geometry is called out clearly.
- Approval is required before any manufacturability-driven geometry change.
- Reference SVGs are labeled as reference-only and not-to-scale when used.
- If a vendor could misread orientation or assembly order, the package includes a marked image, assembly drawing, or direct note.

## 5. Stage-Gate Integrity

- PLA prototype package is judged only for fit, envelope, and assembly validation, not wet-service or thermal proof.
- Hybrid wet-part package is not treated as final-release ready before the real-hose plug test freezes the OD.
- Final wet-part release is blocked until a formal 2D manufacturing drawing or PDF exists.
- Open decisions and measurements that affect manufacturability remain visible in the verdict.

## 6. Verdict Rules

- `Ready to send`: package matches its claimed scope and no blockers remain inside that scope.
- `Quote-ready, not final-release ready`: package is acceptable for a quote or prototype order, but stage-gate or release-document blockers still exist.
- `Not ready`: file drift, missing deliverables, or unresolved blockers make supplier handoff premature.

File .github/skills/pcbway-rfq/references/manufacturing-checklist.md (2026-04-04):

# Manufacturing Checklist

## PCBWay Priority

- if PCBWay asks for assembly drawings, special instructions, or images to remove ambiguity, treat them as required deliverables
- keep units in mm across the package unless the fab explicitly requests otherwise
- if reference SVGs are attached, mark them as reference-only and not-to-scale supplements
- state that manufacturability-driven geometry changes require approval
- keep file names, part names, and package status consistent across CAD, manifest, message text, and drawings

## Plastic Fit Prototype

- include source geometry or exported STL files
- include a fit-only summary
- list every part in the order
- call out hose-plug outer diameters as critical
- state that finish is secondary to dimensional fidelity
- request PLA first when the goal is the lowest-cost fit check
- if reference SVGs are attached, make sure they match the current SCAD geometry and are clearly labeled as reference-only, NTS sheets

## Final Wet Part

- include 3D CAD and 2D drawing
- include clear release metadata: units, material, scale or NTS status, and drawing status or revision
- call out 14.5 mm minimum bore target
- preserve the 6-channel geometry and smooth transitions
- highlight critical-to-function dimensions for bore, transitions, landing face, groove, and hose interface
- specify finish, deburring, sealing, and any leak-test requirement explicitly
- avoid conflicting or duplicate dimensions in the release drawing
- specify wet-surface deburring and landing-face flatness
- state leak-test expectation before shipment

## Controller PCB

- include BOM, Gerbers, centroid file, assembly drawing, and assembly notes
- include special instructions and marked images if orientation or customer-supplied content could be ambiguous
- clarify whether XIAO and Round Display are customer-supplied or fab-sourced
- keep the rev-1 board scoped to logic and interface functions

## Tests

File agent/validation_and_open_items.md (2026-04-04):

# Validation And Open Items

This file captures what still needs to be validated before the project is truly frozen.

## Stage-gate plan

### Gate 1: geometry and hose-fit validation

Required before the final hybrid wet-part order:

- test 16.0 mm hose plug fit on real Fluval hose
- test 15.4 mm hose plug fit
- test 14.8 mm hose plug fit
- confirm the plug roots seat correctly in the trapped pockets before the lid is clamped
- verify insertion depth and clamp access
- verify that the body size fits the intended installation envelope

Output from Gate 1:

- final hose-plug OD decision
- confirmation or revision of block body clearance assumptions

### Gate 2: mechanical CAD freeze

Required before the final hybrid CNC order:

- lock final hose-plug OD
- confirm seal strategy
- confirm screw length and assembly method
- confirm whether any external flats or mounting details are needed

Output from Gate 2:

- release candidate STEP and drawing for stainless machining

### Gate 3: bench thermal bring-up

Required before running on the aquarium:

- verify driver safe default state
- verify hot-side cooling with TEC energized
- verify sensor readings and alarm logic
- leak check water loop
- confirm condensation control plan

Output from Gate 3:

- safe initial duty/current limit for live aquarium testing

### Gate 4: controlled aquarium testing

Required to confirm practical value:

- log room temperature
- log tank temperature
- log hot-side temperature
- log humidity near block
- verify actual achievable temperature below ambient

Output from Gate 4:

- real operating envelope and control tuning

## Open decisions

These are still intentionally unresolved.

1. Final hose-plug OD after prototype hose-plug fit testing.
2. Exact trapped hose-plug interlock geometry and whether the plug root needs a dedicated secondary seal.
3. Exact final seal implementation and released cut length after the wet-part groove is frozen.
4. Logic-threshold compatibility and safe-default behavior on the approved IBT-2 Double BTS7960 43 A driver module.
5. Whether the first controller PCB only conditions signals or also integrates some low-current switched outputs.
6. Leak-threshold calibration and firmware trip policy for the DFRobot SEN0205 prototype sensor.
7. Whether the Round Display is assembled as a direct HMI module at the first PCBWay stage or left as a customer-installed module after the interface board is received.

## Important measurements still needed

1. Actual hose inside diameter on the real Fluval hose when measured with calipers.
2. Actual hose compliance and insertion force on each prototype hose-plug option.
3. Actual installed space around the canister, hose bend radii, and cable routing.
4. Practical enclosure or mounting space for the exact 43 x 43 mm Round Display board and any controller enclosure around it.
5. Measured Double BTS7960 board hole-center spacing and preferred final retention method if the rear-facing windowed mount is later upgraded from the plain ledge support.

## Prototype test checklist

Dry mechanical checks:

- block fits the space
- hose can be pushed on without damage
- clamp can be installed and tightened
- screws are accessible
- insulation can wrap the block cleanly

Electrical checks:

- XIAO powers from its regulated supply correctly
- Round Display powers, initializes, and has readable touch input on the chosen nRF52840 software path
- driver powers safely with outputs disabled
- PWM control behaves predictably
- any level shifting works correctly at 3.3 V logic

Thermal checks:

- TEC polarity is correct
- hot side remains under safe temperature
- cold block develops the expected temperature drop
- no uncontrolled condensation forms outside the insulated region

Hydraulic checks:

- no noticeable pump distress
- no obvious CO2 diffuser backpressure penalty beyond acceptable range
- no trapped-air behavior in the block

## What should not be treated as a success criterion for the plastic prototype print

- final leak-tightness
- final surface finish
- final thermal behavior
- final clamp durability under heat and moisture cycling

## Preferred next engineering tasks after the plastic prototype order

1. Export STEP / STL from the SCAD model and submit the PLA order.
2. Measure and record the actual hose-fit result for all three ODs.
3. Freeze the final metal geometry.
4. Draft the XIAO carrier board concept around the chosen sensors and external driver interface.
5. Produce a stainless-specific drawing package with passivation and leak-test notes.

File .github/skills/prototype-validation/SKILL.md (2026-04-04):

---
name: prototype-validation
description: "Validate the aquarium TEC prototype through staged checks. Use for plastic fit validation, electrical bring-up gates, thermal test sequencing, and recording pass/fail results."
user-invocable: true
---

# Prototype Validation

## When To Use

- reviewing whether the PLA-first plastic order is sufficient
- planning bench bring-up of the controller and driver
- tracking pass and fail criteria before changing geometry or electronics

## Procedure

1. Read `agent/validation_and_open_items.md`.
2. Use [validation-gates.md](./references/validation-gates.md) to stage the work.
3. Record results using [test-record-template.md](./references/test-record-template.md).
4. If the user is really asking whether the project is ready to send out, hand the review off to `manufacturing-readiness-review` instead of treating open gates as resolved.

## Rules

- do not treat plastic prototype parts as proof of sealing or thermal performance
- do not jump to full thermal testing before control and safety defaults are verified
- if reference SVGs are used for geometry review, verify them against the SCAD and keep water-fill overlays clipped to block-owned internal volumes

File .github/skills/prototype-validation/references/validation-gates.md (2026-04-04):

# Validation Gates

## Mechanical Gate

- hose-plug size options tested on the real hose
- hose-plug insertion force acceptable
- clamp access confirmed
- block envelope fits the intended installation space

## Electrical Gate

- regulated rails stable
- controller boots reliably
- display initializes and touch is readable
- TEC driver defaults to disabled at reset
- sensor readings are sane

## Thermal Gate

- hot-side cooling mounted correctly
- condensation monitoring active
- initial TEC tests performed with conservative limits
- water-loop testing only after dry checks pass

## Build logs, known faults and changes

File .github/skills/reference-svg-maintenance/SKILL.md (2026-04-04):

---
name: reference-svg-maintenance
description: "Maintain SCAD-aligned mechanical reference SVGs for this aquarium TEC project. Use for preview SVG fixes, section-view water-path corrections, hose-plug ownership, combined overview cleanup, palette consistency, and XML-safe diagram updates."
user-invocable: true
---

# Reference SVG Maintenance

Use this skill when working on the cold-block SVG reference sheets rather than the underlying solid geometry.

## Procedure

1. Read `tec_cold_block_mockup.scad`.
2. Read `fabrication_notes.md` and `agent/mechanical_design.md`.
3. Read the shared standard in [professional-drawing-and-cad-standards.md](../../references/professional-drawing-and-cad-standards.md).
4. Read the rules in [svg-rules.md](./references/svg-rules.md).
5. Audit the current sheet for header metadata, left/right anchoring, vertical pair alignment, panel spacing, dimension gutters, title gutters, grayscale readability, callout discipline, and note-box capacity before moving labels.
6. Use [svg-review-checklist.md](./references/svg-review-checklist.md) before finalizing edits.
7. Validate edited SVG files as XML.

## Output

- corrected SVG reference sheets
- aligned notes when the diagram had implied the wrong geometry ownership
- reflowed layouts that stay readable at normal zoom and use consistent row anchoring
- professional reference-sheet metadata that makes the sheet status obvious
- updated file references if new preview sheets are added

## Rules

- prefer fixing the drawing to match the SCAD rather than redefining the geometry in prose
- keep section-view blue water overlays inside block-owned internal volumes unless a deliberate split-half comparison is being shown
- keep combined overview sheets derived from the dedicated lid/base/whole-block reference sheets, not looser sketches
- preserve the repo palette and do not mix unrelated colors between sheets
- every SVG reference sheet must declare units in mm, not-to-scale status unless controlled otherwise, the SCAD source of truth, and reference-only status
- do not rely on color alone; the sheet must still read correctly through outlines, labels, and captions
- use short leadered callouts for feature-specific notes instead of leaving descriptive prose floating near geometry
- keep explanatory sentences in note boxes or divider-separated note bands rather than inside the drawing field
- remove superseded or duplicate labels when a stricter formal callout replaces them
- anchor left-side diagrams or note panels to the left edge of their row and right-side diagrams or note panels to the right edge
- vertically center align horizontal pairs of diagrams and/or note panels instead of casually top-aligning mixed-height content
- keep a real title gutter above each diagram so subtitles stay clear of dimension lines and geometry
- enlarge the canvas or redistribute panels before allowing text, notes, dimensions, or guide lines to collide
- split long notes into multiple lines and size note boxes to the final text so nothing overflows

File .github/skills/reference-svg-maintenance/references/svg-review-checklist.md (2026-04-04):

# SVG Review Checklist

## Geometry checks

- Confirm the sheet matches the current SCAD geometry.
- Confirm the channel count shown is six, not five or seven.
- Confirm lid/base ownership and separate hose-plug ownership are shown correctly.
- Confirm the base sheet does not imply straight-channel water volume in the base.
- Confirm the seal groove appears only on the base-oriented sheet.

## Overlay checks

- Confirm blue water fills stay inside the intended internal volume.
- Confirm left and right side overlays follow the same rule within a section.
- Confirm combined sheets reuse the dedicated sheet geometry rather than approximate sketches.

## Annotation checks

- Confirm the sheet header declares units in mm, not-to-scale status or a controlled scale, the source-of-truth model, and reference-only status.
- Confirm screw-hole sizes and counts match the part shown.
- Confirm labels do not contradict the geometry.
- Confirm color is not the only way to understand hidden geometry, water volume, or ownership.
- Confirm feature-specific notes use short leadered callouts where that is clearer than floating prose.
- Confirm explanatory sentences live in note boxes or divider-separated note bands rather than in the drawing field.
- Confirm stricter callouts did not leave duplicate legacy labels behind.
- Confirm view names and section names remain consistent with the rest of the SVG set.
- Confirm left items are left-anchored and right items are right-anchored within each horizontal row.
- Confirm horizontal pairs are vertically center aligned rather than loosely top-aligned.
- Confirm text remains readable and does not collide with dimensions.
- Confirm subtitles stay inside a dedicated header gutter and do not touch dimension lines or geometry.
- Confirm section cuts do not carry long ownership prose when an adjacent note box already covers it.
- Confirm note boxes are tall and wide enough for the final text with no overflow.
- Confirm captions, headers, and dimension labels keep clear gutters and remain readable at normal zoom.
- Confirm the canvas or panel size was increased before allowing guide lines or dimensions to cross text or part geometry.
- Confirm reference dimensions do not create a conflicting manufacturing interpretation.

## Validation

- Parse the edited SVG files as XML.
- If the palette changed, confirm all SVGs still share the same semantic colors.

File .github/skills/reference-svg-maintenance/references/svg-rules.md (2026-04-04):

# SVG Rules

## Professional metadata

- Every reference SVG must show units in mm.
- Every reference SVG must show scale status as not to scale unless a controlled scale is intentionally being maintained.
- Every reference SVG must identify `tec_cold_block_mockup.scad` as the source of truth unless a different source is explicitly stated.
- Every reference SVG must say that it is a reference diagram and not the sole manufacturing drawing.

## Geometry ownership

- The final baseline uses separate trapped hose plugs as distinct parts at both ports.
- The lid owns the six straight channels, the thermal landing, and the upper transition roof.
- The base owns the rectangular seal groove and the lower transition floor.
- The hose plugs are separate parts trapped between lid and base through plug pockets.
- The six straight 56 mm channels are cut into the lid half, not the base.
- The base carries the rectangular seal groove.
- Section views must not imply a continuous cavity in the base under the straight-channel region.

## Water overlays

- Use blue water overlays only for block-owned internal water volume shown by that sheet.
- If a section shows only the base-owned geometry, the water fill must stay inside the base-owned lower volume.
- If a section shows only the lid-owned geometry, the water fill must stay inside the lid-owned upper volume.
- Do not let water overlays float over plug-capture pockets unless the plug or the wetted throat is deliberately being shown.

## Palette

- Outlines and text: charcoal `#1f2933`
- Hidden geometry: blue-gray `#7b90b8`
- Centerlines: muted gray `#98a1af`
- Water: fill `#d9ecff`, stroke `#2563eb`
- Metal faces: light grays `#f7f8fa` and `#e6e9ef`
- Seal features: green `#2f7d4a`
- Thermal / heat zones: fill `#fde1c4`, stroke `#c56a1b`
- Note boxes: near-white `#fcfdff`

## Presentation

- Keep dimension arrows and extension lines in charcoal.
- Keep labels short and tied to actual ownership, not guessed behavior.
- Keep view names and section names explicit and consistent between related sheets.
- Do not rely on color alone; outlines, labels, and line styles must still explain the view in grayscale.
- For a strict formal pass, convert feature-specific prose into short callouts with leader lines where practical.
- Keep sentences and multi-line explanation in adjacent note boxes or divider-separated note bands rather than letting them float through the drawing field.
- Remove duplicate labels after the stricter callout structure is in place.
- If a combined sheet duplicates a lid or base panel, reuse the same proportions and hole layout.
- In a left/right row, anchor the left item to the left working edge and the right item to the right working edge.
- Vertically center align horizontal pairs of diagrams or note panels; do not default to top alignment when the paired items have different heights.
- Give each diagram a dedicated title gutter so subtitles do not touch dimension lines, outlines, or section geometry.
- Keep long ownership explanations out of the section cut itself; put them in the adjacent note box.
- Inside a section view, use labels only for the geometry being pointed at or dimensioned.
- Keep reference-SVG dimensions interpretive and non-conflicting; if release-grade tolerancing is needed, move it into a formal manufacturing drawing.
- Plan gutters for dimensions, captions, and headers before adding more notes.
- Enlarge the sheet or panel footprints before accepting text collisions, note overflow, or lines crossing labels or part geometry.
- Split long prose into multiple lines and size note boxes to the final text; no note text should overflow its box.
